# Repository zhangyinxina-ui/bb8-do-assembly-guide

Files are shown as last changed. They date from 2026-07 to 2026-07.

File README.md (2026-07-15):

# BB-8 & D-O 1:1 Assembly Guide

[中文在线装配网站](https://zhangyinxina-ui.github.io/bb8-do-assembly-guide/) · [English build guide](https://zhangyinxina-ui.github.io/bb8-do-assembly-guide/en/) · [权利与再分发边界](NOTICE.md)

一个面向个人制作者的公开工程记录：包含《星球大战：原力觉醒》BB-8 的 1:1 屏幕参考 Blender 模型、三视图、内部运动机构、运动学/动力学验证、控制器草案，以及 D-O 合法公开资源和采购门控路线。

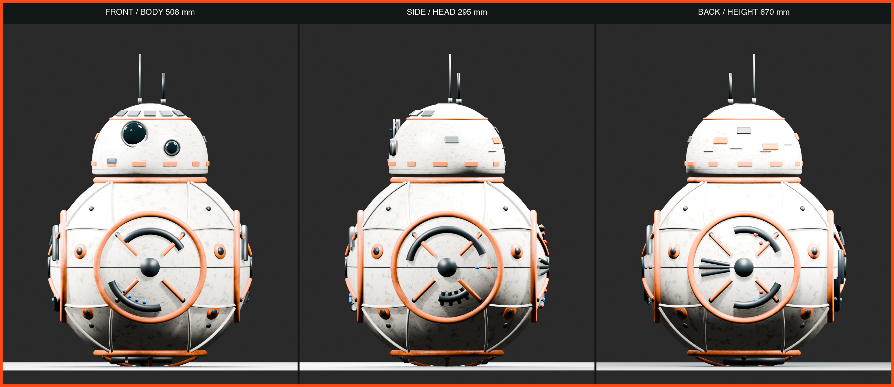
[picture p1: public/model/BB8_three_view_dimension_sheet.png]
BB-8 三视图


## 当前基准

- BB-8 身体球：Ø508 mm。
- 头部最大直径：Ø295 mm。
- 无天线总高：670 mm，对齐 StarWars.com 公开的 0.67 m。
- Blender 主工程 Stage 19 重开审计：386 个总对象、182 个内部对象，其中 150 个制造对象、9 个非制造工程标记和 23 个 `non_fabrication_reference` 预 CAD 门控对象；主文件 SHA-256 为 `ecd9a8b02db7c0b253c06005aaf16e7a8bf10147f8adec9c8900415e18b38af4`。
- 阶段14质量账本：名义8.463 kg、名义质心z=-56.2 mm、最不利角点z=-27.7 mm；0.6 N·m连续扭矩按2×余量时目标加速度降额为0.70 m/s²。17组质量仍需实物称重。
- 双轮差速内车、310 mm 轮距、6+6 磁体随动头和 40 N 装机拉脱力验收合同。
- 编码器轮速 PI + IMU 偏航闭环仿真：直线 RMS 误差 0.00772 m/s、转角 91.20°，传感器过期同周期撤销 PWM。
- ESP32-S3 已编译双正交编码器与 MPU6050 适配；CPR默认为0、静止标定未完成时保持拒动。
- 双 INA226 电流适配、开漏 ALERT、显式限值、过流/堵转回放与11类锁存故障已编译验证；阶段19将原ALERT→EN假设改为适配MDD20A的ALERT_N→PWM许可级，实体测试仍为 `NOT_RUN`。
- 阶段15新增左右电机驱动包络、双散热器、主保险丝、常开接触器、双通道常闭急停、安全继电器、维护断电与系留急停插口；3°动态坡道解析点为0.289 N·m/电机、2.07×连续扭矩裕量和4.22°合成倾角。器件型号与实体测试仍未冻结。
- 阶段16新增19项强制真机调试门、固定字段ESP32遥测解析器和带文件SHA-256的证据审计；当前结果为 `HOLD_PHYSICAL_TESTS_NOT_RUN`，0/19通过。
- 阶段17用厂商官方资料筛选MDD20A、30 A MIDI保险丝、SW60接触器和P28A 4S2P候选；15/15额定检查通过，但因堵转、再生、独立去能适配、BMS与电池包未冻结，结果保持 `HOLD_COMPONENT_FREEZE_MEASUREMENTS_REQUIRED`。
- 阶段18完成REC Active BMS 4S、MDD20A、SW60、MIDI保险丝、外置分流器与双通道门板的模块化电源舱解析布局，并已写入唯一Blender主工程；重开审计确认363个总对象、159个内部对象、150个制造对象、9个工程标记和39个阶段18对象。8个候选包络满足球壳/候选/既有机构间隙门，但12项实物尺寸与接口仍未冻结，结果保持 `HOLD_PHYSICAL_FIT_AND_INTERFACE_VALIDATION_REQUIRED`。
- 阶段19发布双许可PWM门正式KiCad 10原理图与50 × 35 mm两层布线PCB，并把23个非制造板件/器件参考包络写入唯一Blender主工程；重开审计与新导出已通过。SAFE_A、SAFE_B、双INA226 `ALERT_N`与3.3 V掉电均可独立阻断左右PWM；64/64真值组合、0项ERC违规、0项PCB DRC违规、0个未连接项，以及34个器件引用/91条规范引脚连接/21个网络交叉审计通过。但尚无独立原理图/布局同行复核、Gerber/钻孔发布复核、实装板或台架波形，结果保持 `HOLD_PCB_CAD_BENCH_AND_SAFETY_VALIDATION_REQUIRED`。
- 阶段20发现并封锁旧结构分析漂移：当前制造清单的磁力桅杆是Ø24 × 340 mm，而阶段2仍按Ø12/Ø8 × 300 mm铝管计算。新门以当前数字几何筛查2.5 g垂向/1.0 g侧向载荷、斜撑屈曲、纵梁/横梁挠度、PCD35电机安装需求、理想基材疲劳和桅杆模态；解析检查通过，但轮—壳接触还缺5.5 mm径向调节预算，15项材料/连接/公差/实物门全部未关闭，结果保持 `HOLD_JOINT_TOLERANCE_MATERIAL_AND_PHYSICAL_VALIDATION_REQUIRED`。
- D-O v3.4.3 的 D0/D1 舵机—Serial0 冲突已形成固定哈希安全变体：四路舵机移到 D22–D25，Mega 2560 编译仍为 Flash 17% / RAM 18%，并生成版本锁定线束合同；实体导通、USB/Serial0、四路脉宽与失效保护仍为 `NOT_RUN`，不放行舵机电源。
- 24 步装配指南与19项真机门；浏览器进度不能替代真机证据。

这些拆分尺寸和外观细节来自公开画面、社区摄影测量和制作者资料，不是 Lucasfilm 官方 CAD，也不应宣称逐毫米复制电影道具。

## 仓库结构

| 路径 | 内容 |
| --- | --- |
| `blender/` | 参数化生成器、主工程、阶段检查点、审计和导出脚本 |
| `engineering/` | 物理输入、计算结果、D-O 清单和采购门控 |
| `firmware/` | BB-8 C++ 控制核心与 ESP32-S3 适配草案 |
| `docs/` | 从阶段 1 到阶段 20 的中英文设计、验证和续接记录 |
| `hardware/` | 阶段19双许可PWM门正式KiCad原理图、两层布线PCB与OpenSCAD机械包络；不含Gerber/钻孔发布包 |
| `app/` | Vinext/Next 开发网站 |
| `github-pages-src/` | GitHub Pages 纯静态 React 入口 |
| `public/` | 网站公开的图像、GLB、STL、CSV 和说明文件 |
| `tools/` | 运动学、物理、磁耦合、真机证据、D-O 与 Pages 审计工具 |

## 本地运行

要求 Node.js 22.13.0 或更高版本、Python 3，以及可选的 Blender 5.1.x。

```bash
npm ci
npm run dev
```

构建并审计 GitHub Pages 静态网站：

```bash
npm run build:pages
```

完整网站回归测试：

```bash
npm test
npm run lint
```

主要工程验证：

```bash
python3 tools/verify_kinematics.py
python3 tools/verify_physics.py
python3 tools/verify_multibody.py
python3 tools/verify_differential_turn.py
python3 tools/verify_motor_selection.py
python3 tools/verify_magnetic_coupling.py
python3 tools/verify_mass_properties.py
python3 tools/verify_stability_envelope.py
python3 tools/verify_commissioning_evidence.py
python3 tools/verify_power_component_selection.py
python3 tools/verify_power_cassette_layout.py
python3 tools/verify_dual_permissive_gate.py
python3 tools/verify_stage19_kicad.py
python3 tools/verify_stage19_kicad_pcb.py
python3 tools/verify_stage20_structural_load_path.py
python3 tools/audit_do_resources.py
sh tools/run_closed_loop_sim.sh
```

阶段 10 的闭环运动证据见 [编码器 / IMU 闭环运动仿真](docs/BB8_阶段10_闭环运动仿真.md) 和 [200 Hz 遥测](engineering/closed_loop_telemetry.csv)。软件仿真通过不等于真机地面验收。

阶段 11 的传感器代码、默认拒动策略和上电标定顺序见 [ESP32 编码器与 MPU6050 适配](docs/BB8_阶段11_ESP32传感器适配.md) 与 [机器可读接口合同](engineering/sensor_adapter_contract.json)。

阶段 12 的双 INA226、开漏ALERT、显式限值和故障回放见 [电流保护与堵转回放](docs/BB8_阶段12_电流保护与堵转回放.md)、[机器可读电流合同](engineering/power_safety_contract.json) 和 [5 ms回放记录](engineering/power_safety_replay.csv)；当时的EN假设已由阶段19适配为MDD20A的PWM硬件门。

阶段 13 把这条保护链落实到110件内部总成，见 [电流保护硬件建模与重开审计](docs/BB8_阶段13_电流保护硬件建模.md) 和 [110件装配尺寸清单](engineering/internal_assembly_manifest.csv)。

阶段 14 增加可拆卸密封低位配重盒，并以17组质量账本、全部最小/最大角点和刚体惯量替代旧110 mm假设，见 [中文验证报告](docs/BB8_阶段14_质量质心与惯量验证.md)、[English validation report](docs/BB8_stage14_mass_cg_inertia_validation.md) 和 [当前内部装配清单](engineering/internal_assembly_manifest.csv)。

阶段 15 把驱动器与硬件去能链落实为30个新内部对象，并新增斜坡、牵引、转弯、倾角和磁头合载荷扫描，见 [中文阶段15报告](docs/BB8_阶段15_驱动电源与动态稳定性.md)、[English Stage 15 report](docs/BB8_stage15_drive_power_dynamic_stability.md) 和已由阶段19重导出的 [150件制造清单](engineering/internal_assembly_manifest.csv)。未提供机械驻车制动，因此断电坡道保持明确为不支持。

阶段 16 不新增 `.blend` 副本，而是把真实硬件运行转换为19项可审计门：固定字段串口遥测、测量值、证据文件和SHA-256必须同时存在，空填PASS会被拒绝。见 [中文阶段16报告](docs/BB8_阶段16_真机调试证据门.md)、[English Stage 16 report](docs/BB8_stage16_physical_commissioning_evidence_gate.md)、[测试矩阵](engineering/commissioning_test_plan.json)、[证据模板](engineering/commissioning_evidence.json) 和 [当前HOLD结果](engineering/commissioning_results.json)。

阶段 17 将通用电气包络收敛为官方资料支持的候选，但不越过实物证据边界：MDD20A额定裕量足够，却没有独立EN且再生路径未冻结；30 A MIDI必须用堵转波形做I²t配合；SW60普通续流二极管的35 ms典型释放时间超出20 ms合同；4S BMS尚未冻结。见 [中文阶段17报告](docs/BB8_阶段17_驱动电源器件选型门.md)、[English Stage 17 report](docs/BB8_stage17_drive_power_component_selection_gate.md)、[候选矩阵](engineering/power_component_candidates.json) 和 [当前HOLD结果](engineering/power_component_selection_results.json)。

阶段 18 将候选器件收敛为可拆卸模块化驱动电源舱：REC Active BMS 4S按111 × 135 × 44 mm外壳、MDD20A按88.90 × 78.74 mm官方板框、SW60按81 × 37 × 28.1 mm包络进入解析布局。当前最小球壳余量27.643 mm、候选件间隙7.500 mm、与既有机构间隙6.000 mm；这些只证明数字包络未冲突，不代替实物孔位、接插件、线束弯曲、散热与维护验证。几何已覆盖保存到唯一主工程并在重开后通过审计，主文件SHA-256为 `3b774f3e02c89e15922aac48629a43d4765d37078acad88ccf34f6316827d5c3`。见 [中文阶段18报告](docs/BB8_阶段18_模块化驱动电源舱布局门.md)、[English Stage 18 report](docs/BB8_stage18_modular_drive_power_cassette_layout_gate.md)、[布局输入](engineering/stage18_power_cassette_layout.json) 和 [当前HOLD结果](engineering/stage18_power_cassette_results.json)。

阶段 19 将门板占位收敛为正式原理图与布线PCB/DRC参考设计：2个VO617A-4隔离SAFE_A/B，3片SN74LVC2G08依次门控SAFE_A、SAFE_B和双INA226 `ALERT_N`；2.00 kΩ/0.5 W输入支路在12.0–16.8 V解析为5.175–7.900 mA，64行真值表证明任一许可丢失均使两路PWM为低。23个板件/器件包络已作为非制造参考写入唯一主工程，重开后确认386个总对象、182个内部对象、150个制造对象、9个工程标记和23个Stage 19对象；STL/GLB、制造清单与内部三视图已重导出。KiCad 10.0.4正式原理图为0项ERC违规；50 × 35 mm两层PCB含38个封装、1614段走线、54个过孔、F.Cu 3V3和B.Cu GND铜区，DRC为0项违规/0个未连接项。临时重生成板与跟踪板的UUID无关结构哈希一致，XML网表与34个器件引用、91条规范引脚连接和21个网络全部一致。仍没有独立原理图/布局同行复核、Gerber/钻孔发布复核、实装板或20 ms示波器证据。见 [中文阶段19报告](docs/BB8_阶段19_独立双许可PWM硬件门.md)、[English Stage 19 report](docs/BB8_stage19_independent_dual_permissive_pwm_gate.md)、[原理图验证结果](engineering/stage19_kicad_verification.json)、[PCB验证结果](engineering/stage19_kicad_pcb_verification.json)、[PCB DRC报告](engineering/stage19_kicad_pcb_drc.json)、[Blender重开证据](engineering/stage19_blender_reopen_audit.json)、[机器合同](engineering/stage19_dual_permissive_gate_contract.json) 和 [当前HOLD结果](engineering/stage19_dual_permissive_gate_results.json)。

阶段 20 将结构解析重新绑定到当前Stage-19制造清单，并明确标记阶段2的Ø12/Ø8 × 300 mm桅杆已被当前Ø24 × 340 mm包络取代。Ø24/Ø20管材和Ø12/Ø8斜撑只是待冻结候选；2.5 g垂向/1.0 g侧向闭式筛查得到桅杆3.273 MPa、两根纵梁22.814 MPa和0.670 mm挠度，解析裕量通过。PCD35电机面板只报告每颗M4的18.25 N合成需求，不宣称未知等级紧固件已通过。理想6061-T6/T651基材、模态和名义锁扣比值同样只作筛查；轮—壳接触的5.5 mm调节短缺、材料证书、接头、壳体接触、应变、冲击、锤击模态、耐久与19项真机门仍保持开放。见 [中文阶段20报告](docs/BB8_阶段20_结构载荷与公差门.md)、[English Stage 20 report](docs/BB8_stage20_structural_load_and_tolerance_gate.md)、[机器合同](engineering/stage20_structural_load_contract.json)、[当前HOLD结果](engineering/stage20_structural_load_results.json) 和 [载荷扫描](engineering/stage20_structural_load_sweep.csv)。

## D-O 公开资源边界

仓库不冒充拥有 D-O 整机机械文件：

- Printed Droid 公开仓库固定审计到提交 `e90aacdbe26a62fd4f0229d5504a3f2f3c409055`。
- 公开仓库包含 5 个 Arduino 草图，但整机机械 CAD/STL 数量为 0。
- v1.1、v2.1、v3.4 使用个人非商业条款，不能笼统称为 OSI 开源。
- Printed Droid 控制板页的 12 个公开附件已下载到 Git 忽略目录并逐项固定 SHA-256；公开可下载不等于允许本仓库镜像再分发。
- AIO32 v2.1 附件含 22 个源码文件，已用 ESP32 core 3.3.7 实编译通过（Flash 41%、RAM 15%），并发现手册遗漏 SensorLib 依赖；但整包仍无统一 LICENSE、KiCad/Gerber 或机械模型，其手册所称共享仓库硬件文件在当前唯一 `main` 分支中未找到，保持许可与硬件 CAD 双 HOLD。
- Mr Baddeley D-O V2 机械包属于付费资源，本仓库不包含。
- Mantis 播放列表的5集编号构建视频与1个轮胎视频描述已逐条审计；描述没有发布 Matt 改版 CAD 或控制源码，详见 [机器审计](engineering/do_mantis_video_audit.json)。
- 许可不明确的调试支架、第三方 PDF、本地工具链和编译缓存不会推送到 GitHub。

详见 [D-O 资源审计与自组入口](docs/DO_资源审计与自组入口.md)、[D01-D16 自组路线](docs/DO_自组采购与调试路线.md) 和 [26 项采购门控 BOM](engineering/do_self_build_bom.csv)。`DO-SRC-001` 已有 D22–D25 可编译变体但仍等待实体连续性；`DO-SRC-002` 已有版本/哈希绑定线束合同但仍等待逐网导通；`DO-SRC-003` 将官网仍为 v3.4.0 的泛名 ZIP 降为历史参考，当前转换输入只使用固定 GitHub v3.4.3。

## 自动部署

推送到 `main` 后，`.github/workflows/deploy-pages.yml` 会：

1. 安装固定依赖；
2. 构建 `/bb8-do-assembly-guide/` 子路径静态站点；
3. 扫描本机绝对路径、GitHub 令牌和禁止发布的 `.blend` 网站副本；
4. 上传 Pages artifact 并部署到 GitHub Pages。

## 免责声明

这是非官方粉丝研究、个人教育和工程原型。STAR WARS、BB-8、D-O 及相关角色归各自权利人所有。除非文件单独声明许可证，本仓库公开可见不等于自动授予商用、复制或再分发许可。使用前请阅读 [NOTICE.md](NOTICE.md)。

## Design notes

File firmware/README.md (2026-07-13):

# BB-8 双电机控制核心

## 当前状态

`controller_core.*` 是不依赖 Arduino/ESP32 SDK 的控制核心；`sensor_math.*` 是编码器/IMU换算层；`power_safety.*` 是电流阈值、新鲜度与堵转计时层；`esp32_bb8/` 是已通过 ESP32-S3 编译的硬件适配草案。

已实现：

- `v / ω` 到左右轮速差速混控
- 线速度和角速度斜坡限制
- 编码器左右轮速 PI 闭环与 IMU 偏航率差动修正
- IMU/编码器新鲜度和两类偏航测量一致性检查
- 四边沿正交解码、轮速低通、运动指令后750 ms无脉冲停机
- MPU6050地址探测、±4g/±500°/s配置、400样本静止陀螺零偏标定和30 ms超时
- 双 INA226、2 mΩ Kelvin分流、20 ms新鲜度和200 ms寄存器回读门槛
- 每次上电显式配置瞬时电流/堵转电流/持续时间，默认拒动
- INA226 ALERT、测量过流、电流传感器过期和持续堵转锁存
- 左右输出按最大轮速同比例饱和
- 13.2–14.3 V 之间连续功率降额，避免低电量峰值电流触发压降停机
- 12 V 电机母线归一化：4S 满电 16.8 V 时占空比上限 71.4%，避免电机过压
- 急停、遥控丢失、运动传感器过期/不一致、电流传感器过期、硬件电流告警、过流、堵转、欠压、过温、过度倾斜共11类锁存故障
- 只有当所有传感器恢复安全后才允许手动复位

## 本地验证

```bash
clang++ -std=c++20 -Wall -Wextra -Werror \
  firmware/controller_core.cpp tests/controller_core_test.cpp \
  -o build/controller_core_test
./build/controller_core_test
sh tools/run_closed_loop_sim.sh
sh tools/run_power_safety_replay.sh
npm run test:firmware
```

预期输出：

`PASS controller_core: closed-loop feedback, derating, saturation, and 11 fail-safe paths`

闭环仿真会生成 `engineering/closed_loop_telemetry.csv`，电流故障回放会生成 `engineering/power_safety_replay.csv`。两者都是确定性软件证据，不等于真机地面验证。

阶段16把ESP32每200 ms输出的真机遥测扩展为带单调毫秒时间戳的固定字段：命令速度、使能、故障、电池、温度、急停、遥控、IMU、编码器、轮速、电流、硬件ALERT和PWM。将串口监视器原始文本保存后，可运行：

```bash
python3 tools/parse_bb8_telemetry.py \
  --input evidence/run-001/serial.log \
  --output evidence/run-001/telemetry.csv \
  --summary evidence/run-001/telemetry_summary.json
```

解析器只整理真实记录，不会把软件仿真或示例日志转成物理验收PASS。物理记录还必须按 `engineering/commissioning_test_plan.json` 补齐仪表、照片/视频、测量值和SHA-256，再由阶段16验证器审计。

## ESP32 硬件适配合同

200 Hz 主循环必须执行：

1. 更新 RC 帧并计算最后有效帧年龄；超过 100 ms 将 `remote_ok=false`。
2. 从独立常闭急停回路读取 `emergency_stop`；不得只用软件按钮。
3. 电池电压必须经电阻分压和 ADC 标定；默认 4S 欠压门槛 13.2 V。
4. 电机温度传感器脱落必须视为故障，不能当作低温。
5. IMU 与编码器数据必须带时间戳；任一过期或二者偏航率差异超过门槛都必须锁存停机。
6. 两路高侧电流数据必须带时间戳；INA226校准/配置回读错误、未配置限值或数据超过20 ms都必须停机。
7. 两路开漏 ALERT 必须除了进入 GPIO 14，还进入阶段19外部硬件门，直接把MDD20A左右PWM拉低；MDD20A没有独立EN，真正去能仍由安全继电器和常开接触器完成。
8. 调用 `Controller::update(0.005F, command, sensors)`。
9. `enabled=false` 时必须在同一循环内拉低驱动器 EN 硬件引脚，而不只把 PWM 设为零。

## ESP32-S3 编译验证

本项目已用 Arduino CLI 1.5.1 与官方 Arduino-ESP32 3.3.10 对通用 ESP32-S3 目标完成本地编译：

```bash
arduino-cli compile \
  --fqbn esp32:esp32:esp32s3 \
  --config-file .arduino/arduino-cli.yaml \
  --build-path build/esp32_bb8 \
  firmware/esp32_bb8
```

阶段 10 编译结果：程序 338051 bytes（25%），全局变量 22492 bytes（6%）。这只证明源码与当前官方工具链兼容，尚未上传开发板，也未进行带电电机试验。

阶段 11 传感器适配编译结果：程序 367791 bytes（28%），全局变量 24636 bytes（7%）。

阶段 12 电流保护适配编译结果：程序 369971 bytes（28%），全局变量 24676 bytes（7%）。

阶段 16 固定字段真机遥测编译结果：程序 370095 bytes（28%），全局变量 24676 bytes（7%）。

台架串口协议：

1. 上电后保持底盘静止约2秒，等待 `IMU_READY`。
2. 依据实测编码器数据发送 `E <每轮转四边沿计数> <左方向±1> <右方向±1>`；默认CPR为0，未配置时电机EN保持关闭。
3. 依据限流电源下的实测发送 `I <瞬时切断_A> <堵转判定_A> <堵转持续_ms>`；限值默认未配置。
4. 以至少10 Hz发送 `V <线速度m/s> <角速度rad/s>`；先发送 `V 0 0`。
5. 全部传感器安全且最新指令严格为 `V 0 0` 后发送 `R` 清除故障锁存；非零命令下复位会被拒绝。超过100 ms未收到速度帧会停机。

CPR、方向和电流限值都不会写入非易失存储，每次上电都必须重新确认。

## 建议硬件映射（ESP32-S3）

| 信号 | 建议引脚 | 要求 |
|---|---:|---|
| 左 PWM / DIR | GPIO 4 / 5 | PWM 至少 20 kHz |
| 右 PWM / DIR | GPIO 6 / 7 | PWM 至少 20 kHz |
| 驱动 EN | GPIO 8 | 外部下拉，MCU 复位时为禁用 |
| 急停返回 | GPIO 9 | 常闭回路，断线即停机 |
| 左编码器 A/B | GPIO 10 / 11 | 屏蔽双绞线 |
| 右编码器 A/B | GPIO 12 / 13 | 屏蔽双绞线 |
| 电流 ALERT | GPIO 14 | 双 INA226 开漏并联；同时进入阶段19硬件门的 `ALERT_N` 许可级 |
| IMU I²C SDA/SCL | GPIO 17 / 18 | 3.3 V，短线 |
| 电池 ADC | GPIO 1 | 分压+输入保护 |
| 温度 ADC | GPIO 2 / 3 | 左右电机分开采样 |

> 引脚仅是建议映射，必须对照所选 ESP32-S3 开发板原理图排除启动绑定、USB/JTAG 和 Flash/PSRAM 占用引脚。

## 真机前未完成的门槛

- 软件适配已实现并编译，但尚未接入真实MPU6050、编码器和电机验证。只有完成静止标定、显式CPR配置且数据持续新鲜时，`imu_fresh`与`encoders_fresh`才可能为真。
- 当前正交编码器使用GPIO CHANGE中断而不是ESP32 PCNT硬件；必须在目标最高转速下测量中断负载和丢计数，再决定是否迁移到PCNT。
- INA226适配、软件过流/堵转判定和ALERT配置已编译；阶段19已给出ALERT/SAFE_A/B→PWM预CAD合同，但实体2 mΩ分流、Kelvin布线、正式PCB、驱动器硬限流与急停回路仍未验证。
- 必须在轮子架空时标定方向、比例和电流上限。
- 必须有物理急停、保险丝、独立驱动 EN 和围栏后才可落地。

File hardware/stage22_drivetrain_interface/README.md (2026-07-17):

# Stage 22 drivetrain interface

This package corrects the Stage-21 non-catalogue `5M-280-15` belt candidate and closes the analytical bearing, shaft, key and rail-interface load path. It is **reference CAD only**, not a fabrication release.

The selected reference architecture uses:

- Gates `5MGT-300-15`, product `92706002`, 300 mm pitch length, 60 teeth and 15 mm width;
- equal candidate 24-tooth 5MGT pulleys at 90 mm centre distance;
- two candidate 6001 sealed bearings per cassette, 38 mm bearing-centre span;
- a 12 mm keyed shaft with candidate 4 × 4 × 20 mm DIN 6885 key engagement;
- two 6 mm reamed dowels, four M6 clamps and a hard stop per cassette;
- a removable outboard pulley and guard for safe belt installation.

## Build the reference outputs

Run:

```sh
tools/build_stage22_drivetrain_interface_cad.sh
```

The dependency-light builder creates two nominal DXF profiles, a keyed-shaft envelope STL, an assembly-envelope STL, an engineering review PNG and a SHA-256 manifest in `outputs/`. The editable OpenSCAD source is supplied alongside them.

## Assembly order

1. Machine the shaft, keyway, hubs, bearing seats, retainers and rail bracket only after supplier fit tables, material certificates and GD&T are frozen.
2. Press or slide the selected bearings using the supplier-prescribed ring support; retain the outboard bearing and preserve at least 0.3 mm axial float at the inboard bearing.
3. Install the wheel hub between the bearing supports, then fit the keyed shaft and positive axial retainers.
4. Locate the cassette with both 6 mm dowels and the hard stop before tightening the four M6 clamps.
5. Fit the motor pulley, wheel pulley and belt as one serviceable stack by removing the outboard pulley and guard; never force the belt over two flanges.
6. Set belt tension from Gates DesignFlex or a supplier calculation, then record the measurement method and cold/hot values.
7. Perform the 7.2 Nm keyed-joint torque proof, raised-wheel spin/e-stop test, shell clash/service audit and the complete nineteen-item physical commissioning gate.

## Release boundary

The analytical screen passes, but supplier power rating and installation tension, bearing clearance and fits, shaft/hub drawings, materials, dowel ream and GD&T, guard fasteners and service access, Blender clash, tire/shell wear, yaw calibration, thermal/endurance and physical commissioning remain on HOLD. The user's current Blender master is intentionally not changed or saved by Stage 22.

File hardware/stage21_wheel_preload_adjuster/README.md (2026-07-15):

# Stage 21 tangent-wheel preload cassette

This directory contains **reference CAD only** for the Stage-21 BB-8 powered-wheel correction. It is not a fabrication release.

The current Blender wheel is a 96 × 26 mm finite cylinder with its axle along global X. Exact support geometry leaves about 5.07 mm to the 254 mm inner shell and the axle misses the local tangent plane by about 48.8°. The reference cassette therefore:

- cants the wheel axle tangent to the local shell;
- moves the IG42 motor 80 mm radially inward on a parallel axis;
- uses candidate equal 24T, 5 mm-pitch pulleys and a 280 mm / 56-tooth belt;
- carries the wheel on two candidate 6001-2RS bearings and a 12 mm shaft;
- gives 12 mm radial travel with an M6×1 jackscrew, hard stops and four M6 clamps;
- uses a 0.75 mm parabolic crown drop across the 26 mm wheel width.

## Build the reference outputs

Run:

```sh
tools/build_stage21_wheel_preload_cad.sh
```

When OpenSCAD is available, the script exports the assembly, fixed/moving plates, jackscrew block, crowned-wheel envelope, two DXF profiles and a review PNG into `outputs/`.

If OpenSCAD is unavailable, the checked-in Python fallback creates exact 2D DXF cut profiles, an exact crowned-wheel STL, reference-envelope STL files and the review PNG without installing anything. In that fallback, the plate STL files are deliberately named `*_envelope.stl`: use the DXF—not the envelope STL—for holes and slots.

## Safety and release boundary

The DXF and STL files are fit references. Do not manufacture a running robot from them until the open gates in `engineering/stage21_wheel_preload_contract.json` are closed. In particular, bearing fits, shaft/hub retention, belt rating and tension, guards, plate material, M6 preload, shell contact strength, tire compound and measured 60–100 N wheel preload are not frozen. The current open Blender master is intentionally not modified by this package.

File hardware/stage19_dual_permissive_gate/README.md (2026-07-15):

# Stage 19 dual-permissive PWM gate — routed PCB/DRC reference design

This package replaces the Stage-18 empty gate-board placeholder with a reviewable electrical contract, deterministic KiCad 10 schematic and a real 50 × 35 mm two-layer routed PCB. KiCad 10.0.4 reports **0 ERC violations, 0 PCB DRC violations and 0 unconnected items**. The 34 electrical references, 91 pin assignments and 21 named nets match the canonical CSV; the PCB adds four contracted 3.2 mm M3 NPTH mounting holes. It is deliberately **not a fabrication release**: independent schematic/layout peer review, intentional Gerber/drill review, fabrication, continuity, power-up and bench waveforms remain absent.

## Intended function

```mermaid
flowchart LR
  MCU[MCU PWM L/R] --> A[U3: AND SAFE_A_OK]
  A --> B[U4: AND SAFE_B_OK]
  B --> C[U5: AND ALERT_N]
  C --> MDD[MDD20A PWM L/R]
  SA[12–16.8 V permissive A] --> OA[VO617A-4 A]
  SB[12–16.8 V permissive B] --> OB[VO617A-4 B]
  OA --> A
  OB --> B
  INA[Dual INA226 open-drain ALERT] --> C
  REL[Safety relay] --> SA
  REL --> SB
  REL --> SW60[Normally-open main contactor]
```

Both outputs follow:

`PWM_OUT = LOGIC_POWER_OK AND PWM_IN AND SAFE_A_OK AND SAFE_B_OK AND ALERT_N`

Either safety channel, a current ALERT, or loss of 3.3 V forces both PWM outputs low. `DIR_L` and `DIR_R` pass through directly and are not safety signals. The contract therefore requires MDD20A sign-magnitude mode, where PWM low is brake.

The board provides six declared test points: `SAFE_A_OK`, `SAFE_B_OK`, `ALERT_N`, `PWM_L_OUT`, `PWM_R_OUT` and `GND`. The PCB-plus-component envelope is 11.4 mm; including the 3.0 mm insulated mounting stack gives 14.4 mm installed height and only 0.6 mm analytical margin inside the Stage-18 keepout.

## Safety boundary

- PWM low is braking, not energy isolation. The independent safety relay and normally-open contactor must still remove the motor bus.
- This is not a safety PLC, certified safety relay or redundant safety controller. Shared power, PCB, connectors, logic packages and the motor driver remain common-cause paths.
- The VO617A-4 CTR and saturation checks in this repository use the manufacturer's 25 °C test points. Its saturated 25 µs turn-off is a typical value, not a guaranteed maximum.
- An open `ALERT_N` wire can be pulled high by R13; that path is not fail-safe. Commissioning must test the sensor harness and MCU freshness latch separately.
- Do not fabricate or energise from these files. The formal schematic, routed layout and DRC are complete as a digital reference, but an independent peer review and intentional Gerber/drill release must happen before any manufacturer order or Stage-E02 bench test.

## Files

- `engineering/stage19_dual_permissive_gate_contract.json` — source-of-truth requirements and official references.
- `engineering/stage19_gate_netlist.csv` — pin-level connectivity contract.
- `engineering/stage19_gate_bom.csv` — provisional BOM; many passives remain manufacturer-TBD.
- `engineering/stage19_gate_truth_table.csv` — all 64 input combinations.
- `engineering/stage19_dual_permissive_gate_results.json` — analytical result and unresolved release gates.
- `stage19_dual_permissive_gate.kicad_sch` / `.kicad_pro` / `.kicad_pcb` — formal KiCad 10 schematic and routed two-layer PCB project.
- `stage19_symbols.kicad_sym` — project-local custom MCU-header and VO617A-4 symbols used by the deterministic capture.
- `engineering/stage19_kicad_erc.json` — KiCad 10.0.4 ERC export with zero violations.
- `engineering/stage19_kicad_netlist.xml` / `stage19_kicad_bom.csv` — machine-audited connectivity and KiCad BOM exports.
- `engineering/stage19_kicad_pcb_drc.json` — KiCad 10.0.4 PCB DRC report with zero violations and zero unconnected items.
- `engineering/stage19_kicad_pcb_verification.json` — structural regeneration, board envelope, mounting-hole, net and DRC evidence.
- `output/pcb/BB8_stage19_gate_pcb_*` — top/bottom copper review plots and a visually inspected isometric render; review images only, not Gerbers.
- `output/pdf/BB8_stage19_dual_permissive_gate_schematic.pdf` — reviewed one-page A4 schematic rendering.
- `tools/verify_stage19_kicad.py` — regenerates, runs ERC/exports and cross-audits the canonical netlist without granting fabrication release.
- `tools/generate_stage19_kicad_pcb.py` — deterministically places and routes the PCB with real KiCad footprints.
- `tools/verify_stage19_kicad_pcb.py` — regenerates the PCB in a temporary directory, compares UUID-independent structure and runs DRC on both copies.
- `tools/export_stage19_kicad_pcb.py` — exports review SVG/PNG files only; it cannot emit Gerber or drill manufacturing data.
- `tools/verify_dual_permissive_gate.py` — deterministic evaluator.
- `board_envelope.scad` — deterministic component-envelope model source. The local OpenSCAD 2021.01 CLI did not complete a headless export, so no STL is claimed in this stage.

## Required next tests

1. Independent peer review of the captured KiCad schematic and its safety assumptions.
2. Independent PCB placement/routing, creepage, courtyard, connector-polarity and test-point peer review; the automated DRC result alone is not release approval.
3. Intentionally generate and manually review Gerber/drill plots before any manufacturer order; none is published in this reference package.
4. Unpowered continuity and polarity inspection.
5. 12.0 V and 16.8 V corner tests for `SAFE_A` and `SAFE_B` independently.
6. Oscilloscope proof that each safety channel, `ALERT_N`, logic-power loss and MCU stuck-high drive both PWM outputs low within 20 ms.
7. 20 kHz PWM integrity, temperature, vibration, connector retention and EMC checks.
8. Combined safety-relay/contactor/PWM-gate Stage-E02 evidence.

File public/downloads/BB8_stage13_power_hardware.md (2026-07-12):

# BB-8 阶段 13：电流保护硬件建模与重开审计

> 结论：**双 INA226、双 2 mΩ 四线分流器、开漏 ALERT 汇接和独立驱动 EN 门已落实为 Blender 内部安装包络，并通过关闭后重新打开审计；真实板卡接线、脉冲额定、堵转和热试验仍为 `NOT_RUN`。**

## 新增的 22 个内部对象

| 对象组 | 数量 | 建模包络/合同 |
|---|---:|---|
| INA226 电流监测板 | 2 | 34 × 22 × 1.6 mm；地址 `0x40` / `0x41` |
| Kelvin 分流器 | 2 | 12 × 5 × 3 mm；2 mΩ、四线采样 |
| M2.5 可拆支柱 | 6 | 3 mm 安装高度；两监测板各2个，门板2个 |
| ALERT→EN 硬件门板 | 1 | 28 × 14 × 1.6 mm；MCU 停止执行时仍须能拉低双驱动 EN |
| 受监测高侧电源线 | 4 | 左右支路各输入/输出1条；最小弯曲半径30 mm |
| Kelvin 采样线 | 4 | 左右分流器各正/负1条；不可与大电流压降共用测量点 |
| 开漏 ALERT 线 | 2 | 左右 INA226 线与后汇接到硬件门 |
| 独立驱动 EN 线 | 1 | 失效低电平同时关闭两路驱动 |

这些对象安装在现有 104 × 80 × 12 mm 电子托盘上，板底与托盘顶面保持 3 mm 支柱间隙，并继承内车 `-4° → +4°` 俯仰动画。模型对象带有 `physical_test_status=NOT_RUN`，防止把几何布置误写成实物验证。

## 重开审计门

`blender/audit_bb8.py` 现在同时检查：

- 内部对象不少于110件，总对象保持314件；
- 两块 INA226 地址恰为 `0x40` / `0x41`；
- 两个分流器均为2 mΩ、四线连接，并保留脉冲额定实测门；
- 11条保护线的种类和数量固定为输入2、输出2、Kelvin 4、ALERT 2、EN 1；
- 三块电路板都落在电子托盘占地范围内，板底间隙为3 mm；
- 场景级实体试验状态必须保持 `NOT_RUN`；
- 原有508/295/670 mm、6个主面板、8个角区、驱动/磁头/线束和球壳包络门继续通过。

重开结果：

```text
PASS reopenable_blend engineering_stage=13 objects=314 internal=110 panels=6 triangles=8 rings=3/2/1 body=508mm head=295mm height=670mm
```

## 可追溯输出

- 主工程：`blender/output/BB8_1to1_screen_referenced.blend`
  - SHA-256：`5653ae72b029a4c770382bb6525e142e55fed60b0225811d9fb1149bd0434eac`
- 最终检查点：`blender/checkpoints/BB8_stage13_power_safety_hardware_v3.blend`
  - SHA-256：`244acfb60c706770e6bd03c08c76cb9eb8e049152bcd78e71a8b00bc60fa28e7`
- 内部机构 STL：`blender/exports/BB8_internal_mechanism_mm.stl`
  - SHA-256：`4427cc7410c61d39281e6c22748d0ca548c1616383fa8e3295839d79f5b226e4`
- 动画 GLB：`blender/exports/BB8_1to1_kinematic.glb`
  - SHA-256：`1585a883fb4cd93ae3380fb1d2773486e598ddf5707e7d9f7e959b1dcdc73de1`
- 自动装配清单：`engineering/internal_assembly_manifest.csv`，共110行对象记录。

## 下一道实体门

只有拿到真实 INA226 模块、2 mΩ 分流器、驱动器、电机、电池和线束后，才可执行：四线焊点核验、零点/量程标定、ALERT 断 MCU 试验、分流器脉冲温升、保险丝配合、架空堵转和封壳热平衡。未完成这些项目时，不得把本阶段标记为“硬件保护验证通过”。

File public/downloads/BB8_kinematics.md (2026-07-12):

# BB-8 运动学、控制架构与验证

## 设计边界

本方案是可制造的社区复刻架构：低重心双轮内车驱动球壳，顶部磁性桅杆耦合头部。它不是《原力觉醒》电影道具未公开的内部设计。

## 直线滚动关系

球体无滑动滚动：

`s = Rb · θb`

- `Rb = 0.254 m`
- 球体旋转 `360°` 的理论位移：`2πRb = 1.59593 m`
- 内部驱动轮半径 `Rw = 0.048 m`
- 球体一周对应驱动轮理论转数：`s / (2πRw) = 5.29167`

Blender 动画用线性插值将这一关系锁定在 1–120 帧（30 fps）：

- `RIG 00 - World travel`：位移 1.59593 m
- `RIG 10 - Rolling ball`：旋转 360°
- 两个 `Internal drive wheel`：各旋转 5.29167 周
- `RIG 20 - Gravity stabilised chassis`：加速时俯仰 -4°，匀速 0°，制动 +4°
- `RIG 30 - Magnetically coupled head`：保持世界竖直姿态目标

## 差速转向

左右驱动轮的外层控制可用标准差速映射：

`v = (vr + vl) / 2`

`ω = (vr - vl) / B`

`B` 是内车两轮接触中心间距。但内车通过球壳间接驱动地面，所以真机必须用编码器 + IMU 标定一个经验映射系数 `k_shell`，不能只靠开环理论值。

## 控制环

1. **200–500 Hz 安全环**：遥控丢包、倾角、过流、欠压、过温任一触发即零扭矩。
2. **200 Hz 电机速度环**：编码器 PID 左右独立闭环。
3. **100–200 Hz 车体姿态环**：IMU 估计内车俯仰/滚转，限制加速度防止内车翻越。
4. **50–100 Hz 头部目标环**：在磁耦合能力范围内保持头部质心位于球顶安全锥内。
5. **20–50 Hz 遥控命令环**：对速度和转向加斜坡限制，不直接跳变扭矩。

## 质心与稳定性验收

- 内车总质心建议低于球心 80–150 mm。
- 静止时将内车偏转 10°，释放后必须自动回复，无线束卡滞。
- 头部磁性载台在最大设计加速度下不得越过头底滚轮支撑多边形。
- 任一传感器故障不得让电机保持上一帧非零命令。

## 首台样机的保守运行包络

| 阶段 | 最高速度 | 最高加速度 | 头部 | 验收后才可进入 |
|---|---:|---:|---|---|
| 架空 | 轮子 10% PWM | 无 | 不安装 | 方向、编码器、急停正确 |
| 围栏内低速 | 0.10 m/s | 0.10 m/s² | 不安装 | 连续 10 次起停无翻车 |
| 围栏内跟头 | 0.15 m/s | 0.10 m/s² | 泡沫配重头 | 不脱落、不夹伤 |
| 室内样机 | 0.30 m/s | 0.20 m/s² | 完整头 | 急停距离和温升达标 |

## 数值验证

运行：`python3 tools/verify_kinematics.py`

输出 `blender/output/kinematics.csv`，并对一周位移、球体转角和驱动轮转数执行断言检查。

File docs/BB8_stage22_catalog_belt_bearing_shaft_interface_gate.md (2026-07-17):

# BB-8 Stage 22: Catalog Belt, Dual-Bearing Keyed Shaft and Rail Interface Gate

> **HOLD_SUPPLIER_FITS_TENSION_TORQUE_PROOF_AND_PHYSICAL_INTEGRATION_REQUIRED**. Catalog geometry, bearing life, keyed-shaft strength, positive rail load path and shell-envelope screens pass. Fabrication, Blender integration and physical release remain blocked.

## Correcting the Stage-21 belt candidate

- Gates' 2025 industrial catalog starts its standard 15 mm-wide 5MGT list at 300 mm. The Stage-21 **5M-280-15 / 280 mm / 56-tooth** candidate is not in that stock-length table.
- The replacement is official part **5MGT-300-15**, product 92706002: 300 mm pitch length, 60 teeth and 15 mm width.
- Equal 24T, 5 mm-pitch pulleys have 38.197 mm pitch diameter. A 90 mm center distance gives exactly **300.0 mm** closed pitch length at 1:1.
- Twenty-four teeth exceed Gates' 18-tooth 5MGT minimum recommendation. The motor mount provides 4.0 mm total adjustment, exceeding the catalog's 1 mm tensioning allowance.
- Do not force the belt over two flanges. Remove the guard and outboard wheel pulley, then install the belt together with that pulley. Gates DesignFlex or supplier power and installation-tension calculations remain mandatory.

## Dual 6001 bearing and overhung-pulley load path

- Conservative rating floors come from SKF W 6001-2RS1: 12×28×8 mm, C=4.42 kN, C0=2.36 kN and 16000 r/min limiting speed. This does not claim an SKF purchase.
- Bearing centers are 38 mm apart and the pulley center overhangs the outboard bearing by 14.5 mm. Three-times shock torque plus an 80 N-per-span pretension ceiling creates a 348.5 N pulley envelope and **532.8 N** worst equivalent bearing load.
- Static safety is 4.43; analytical L10 is **9516 h** even at 1000 r/min. Clearance, seals, fits, misalignment, contamination and temperature still require selected-part evidence.

## 12 mm keyed shaft, hubs and positive rail interface

- Under 3.6 N·m shock torque, pulley overhang and 100 N wheel preload, the ideal bending-torsion von Mises stress is 40.1 MPa. A 2.5 keyway factor raises it to **100.2 MPa**. Requiring certified yield of at least 400 MPa gives 3.99 analytical safety.
- A 4×4×20 mm key sees 7.5 MPa shear and 15.0 MPa bearing stress. A physical 7.2 N·m no-slip, no-permanent-set torque proof remains required.
- Each cassette uses two 6 mm dowels, four M6 clamps and a hard stop. At 1000 N interface load, dowel shear is 17.7 MPa, plate bearing 13.9 MPa and tear-out 4.6 MPa. No interface friction is credited.

## Packaging and assembly limits

- Moving to 90 mm center distance leaves 102.0 mm motor clearance, 13.1 mm plate clearance and 20.8 mm guarded-pulley clearance.
- These are local analytical envelopes, not a full current-master clash pass. Stage 22 did not save or overwrite the user's Blender master.

## Maker assembly and verification sequence

1. Cut inexpensive fit-test profiles first and confirm 90 mm center distance, 24T pulleys, the 300 mm belt and removable-pulley installation order.
2. Freeze the 12 mm shaft and 28 mm housing fits from the selected bearing supplier; locate one bearing and allow at least 0.3 mm float at the other, then measure endplay and outer-ring creep.
3. Machine the certified 12 mm keyed shaft and 4×4 keys, and pass the 7.2 N·m bench torque proof before installing the tire.
4. Feed each 1000 N cassette load into the chassis through two dowels and a hard stop; M6 fasteners clamp only. Guard removal must require isolated power.
5. Only then run raised-wheel belt tracking, E-stop, thermal, shell-contact, low-speed yaw-identification and nineteen-item commissioning tests.

Open freeze gates: 13. Manufacturing release is false and physical status is NOT_RUN.

## Official sources

- Gates 5MGT-300-15 product page: https://www.gates.com/us/en/power-transmission/synchronous-belts/poly-chain-synchronous-belts.p.9270-000000-000001.v.9270-06002.html
- Gates 2025 industrial catalog: https://www.gates.com/content/dam/documents-library/catalogs/industrial-power-transmission-catalogue-en.pdf
- Gates PowerGrip GT3 design manual: https://www.gates.com/content/dam/documents-library/catalogs/powergrip-gt3-drive-design-manual-en.pdf
- Gates preventive-maintenance manual: https://www.gates.com/content/dam/gates/home/knowledge-center/resource-library/operating-manuals/preventive-maintenance-manual-en.pdf
- SKF stainless deep-groove ball-bearing catalog: https://www.skf.com/binaries/pub12/Images/0901d19680406705-SKF-Stainless-steel-DGBB---11279_1-EN-Low-Res_tcm_12-259995.pdf

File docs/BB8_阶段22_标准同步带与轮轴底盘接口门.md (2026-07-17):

# BB-8 阶段 22：标准同步带、双轴承键轴与底盘接口门

> **HOLD_SUPPLIER_FITS_TENSION_TORQUE_PROOF_AND_PHYSICAL_INTEGRATION_REQUIRED**。目录几何、轴承寿命、键轴强度、正向定位接口与球壳包络解析筛查通过；制造、Blender写入和真机验证仍未放行。

## 先纠正阶段21的皮带候选

- Gates 2025工业目录的15 mm宽5MGT标准长度从300 mm起；阶段21的 **5M-280-15 / 280 mm / 56齿** 不在该标准库存长度表中。
- 改用官方产品 **5MGT-300-15**（产品号 92706002）：300 mm节线、60齿、15 mm宽。
- 两只24T、5 mm节距等径带轮的节径为 38.197 mm；90 mm轴距精确得到 **300.0 mm** 闭式节线，传动比仍为1:1。
- 24齿高于Gates对5MGT的18齿最小建议。电机安装位提供 4.0 mm总调节，超过目录的1 mm张紧余量。
- 双法兰条件不允许强行把皮带撬过法兰；规定先拆防护罩和轮侧可拆带轮，带轮与皮带一起装回。额定功率和安装张力仍必须用Gates DesignFlex或供应商计算冻结。

## 双6001轴承与悬臂带轮载荷

- 用SKF W 6001-2RS1的较保守目录值作评级下限：12×28×8 mm，C=4.42 kN，C0=2.36 kN，极限转速16000 r/min；未声称已经采购SKF轴承。
- 轴承中心跨距38 mm，带轮中心比外侧轴承悬出14.5 mm。3×冲击扭矩和每跨80 N预紧上界形成 348.5 N带轮径向包络，最重外侧轴承等效载荷 **532.8 N**。
- 静强度安全系数 4.43；即使按1000 r/min解析，L10仍为 **9516 h**。这不替代游隙、密封、配合、偏心、污染和温升实测。

## 12 mm键轴、轮毂与正向底盘接口

- 12 mm轴在3.6 N·m冲击扭矩、带轮悬臂和100 N轮压下，理想弯扭von Mises为 40.1 MPa；乘2.5键槽系数后为 **100.2 MPa**。要求材料证书屈服强度至少400 MPa，解析安全系数 3.99。
- 4×4×20 mm平键需求为剪应力 7.5 MPa、挤压应力 15.0 MPa；最终仍要做7.2 N·m无滑移、无永久变形的实物扭矩证明。
- 每侧底盘接口用2根6 mm定位销、4颗M6夹紧和一个硬限位；1000 N设计载荷下，定位销单剪 17.7 MPa、6 mm板孔挤压 13.9 MPa、边缘撕裂 4.6 MPa。强度筛查不借用摩擦力。

## 包络与装配限制

- 电机轴距增至90 mm后，电机球壳解析余量为 102.0 mm；板件最小余量 13.1 mm；含3 mm防护罩余量的带轮最小余量 20.8 mm。
- 这些是局部解析包络，不是当前用户Blender主工程的完整干涉通过结论；本阶段没有保存或覆盖该主文件。

## 自组装与验证顺序

1. 先按参考DXF做廉价样板，确认90 mm轴距、24T带轮、300 mm皮带和可拆轮侧带轮的装配顺序。
2. 用选定轴承供应商的配合表冻结12 mm轴和28 mm座孔；一端固定、一端至少0.3 mm浮动，再测端游和外圈爬动。
3. 加工带证书的12 mm键轴与4×4键，先在台架做7.2 N·m扭矩证明，再装轮胎。
4. 用两根定位销和硬限位把每侧1000 N载荷送入车架，M6只负责夹紧；检查防护罩必须在断电后才能拆。
5. 之后才允许进行架空皮带跑偏、急停、温升、球壳接触、低速偏航辨识和19项整机调试。

开放冻结门：13项；制造发布为否，物理试验状态为NOT_RUN。

## 官方来源

- Gates 5MGT-300-15产品页：https://www.gates.com/us/en/power-transmission/synchronous-belts/poly-chain-synchronous-belts.p.9270-000000-000001.v.9270-06002.html
- Gates 2025工业传动目录：https://www.gates.com/content/dam/documents-library/catalogs/industrial-power-transmission-catalogue-en.pdf
- Gates PowerGrip GT3设计手册：https://www.gates.com/content/dam/documents-library/catalogs/powergrip-gt3-drive-design-manual-en.pdf
- Gates预防维护手册：https://www.gates.com/content/dam/gates/home/knowledge-center/resource-library/operating-manuals/preventive-maintenance-manual-en.pdf
- SKF不锈钢深沟球轴承目录：https://www.skf.com/binaries/pub12/Images/0901d19680406705-SKF-Stainless-steel-DGBB---11279_1-EN-Low-Res_tcm_12-259995.pdf

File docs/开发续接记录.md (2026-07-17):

# BB-8 / D-O 开发续接记录

更新时间：2026-07-12 19:30（Asia/Shanghai）

## 当前可继续的主工程

- Blender：`blender/output/BB8_1to1_screen_referenced.blend`
- 建模生成器：`blender/create_bb8.py`
- 导出器：`blender/export_bb8.py`
- 重开审计：`blender/audit_bb8.py`
- 网站：`app/page.tsx`
- 物理参数：`engineering/physics_inputs.json`
- 物理验证器：`tools/verify_physics.py`

## 本阶段证据

- Blender 后台重开审计成功：292 个对象、88 个内部机构对象；GUI 同一进程无损重开阶段 9.3 主工程，当前仅 1 个 Blender GUI 进程且窗口无未保存星号。
- 场景元数据与可见几何：球体 508 mm、头部 295 mm、不含天线高度 670 mm。
- 身体、头部和内部机构 STL 以及 GLB 已从当前主工程重新导出，不再沿用旧外观文件。
- 阶段 1 物理解析模型在当前假设下 PASS：8.57 N 推进力、每电机 0.286 N·m、连续扭矩裕量 2.10×、磁保持裕量 2.51×。
- 网站构建及 2 项渲染回归测试通过。

## 文件指纹

- 主 `.blend`：`c4dd9fbd9a6f931992797ecbfa96d5a3559686047a40362821e7706e4b236ff0`
- 阶段 1 检查点：`6abceb677bfdd6b6bf13d89373fd49696c4f7c623092c28a5e4edbe72d4c5560`
- 阶段 2 检查点：`3ab31459d9aff2f7e7e3c92db93c5a4ac870eb6c74bf05abbb9dc13deb366133`
- 内部机构 STL：`4f5b67a637651efc8a223c7a63739cd1a7ba028972a56c118726261b8b7b0975`

## 未完成且不得误称完成

1. 外观仍是屏幕参考重建，尚未达到逐面板电影道具测绘精度。
2. 物理 PASS 基于假设输入，不是实物认证；需要称重、摩擦/预紧、扭矩电流、磁脱离力实测。
3. 编码器/IMU闭环、双INA226电流适配、过流/堵转回放和ESP32-S3编译已完成，但实体接线、参数辨识、ALERT→EN硬件门、热平衡、壳体接触/疲劳仍未完成。
4. D-O 付费 CAD 尚未购买；公开网站已部署到 `https://zhangyinxina-ui.github.io/bb8-do-assembly-guide/`。

## 下一步

拿到真实目标板、电机、驱动器、电池、MPU6050、编码器和双INA226板后，先核对GPIO/I²C、分流器额定与ALERT→EN外部门，再完成架空轮CPR/方向/IMU/电流标定，用阶跃响应替换仿真参数，随后进入封壳围栏低速验证。

## 阶段 2：多体、结构与电热（2026-07-12 14:27）

- 新增 `tools/verify_multibody.py`、`docs/BB8_多体结构电热验证.md` 和 `engineering/turning_multibody_sweep.csv`。
- 1.0 m/s、0.6 rad/s 转弯及冲击合载荷下，磁头解析保持裕量 2.31×。
- 12/8 mm、300 mm 铝管桅杆解析静态屈服裕量 18.52×；尚未计入疲劳、孔位和模态降额。
- 电机集总热模型估算设计点 38.9 °C。
- 低电量峰值电流会把 4S 电池拉到 12.55 V；控制核心已加入 13.2–14.3 V 连续功率降额并重新通过 ESP32-S3 编译。
- 阶段参数与扫描快照保存在 `engineering/checkpoints/stage02_multibody/`。

## 阶段 3：参数化内部总成（2026-07-12 14:31）

- 内部机构从 9 个示意对象增加到 25 个稳定标记对象。
- 新增左右电机座、四只随动稳定轮及支撑臂、左右桅杆三角支撑、两条电池固定带、电子托盘和保险丝/接触器包络。
- 生成内部正视、侧视、俯视三视图及组合图 `blender/output/BB8_internal_three_view.png`。
- 新增 `engineering/internal_assembly_manifest.csv`，记录每个机构对象的包络尺寸和世界坐标。
- 阶段检查点：`blender/checkpoints/BB8_stage03_buildable_internal_assembly.blend`。

## 阶段 4：真实电机候选与接触几何（2026-07-12 14:42）

- 厂家数据筛选首选候选：Sha Yang Ye / Cytron `IG42E-24K`，12 V、248 rpm、0.98 N·m额定扭矩、5.5 A额定电流。
- 96 mm轮理论额定地速1.25 m/s；相对0.286 N·m连续需求的额定扭矩裕量3.43×。
- Pololu 4692最大效率点扭矩约0.186 N·m，未作为当前连续工况首选。
- 内部电机包络更新为42 mm直径、100 mm保守总长、8 × 20 mm轴；对象数增至27。
- 修复此前驱动轮悬空问题：驱动轮中心位于206 mm接触半径，四只稳定球中心位于236 mm接触半径，审计公差±1 mm。
- 固件新增12 V电机母线归一化；4S满电16.8 V时PWM上限71.4%，ESP32-S3重新编译通过。
- 阶段检查点：`blender/checkpoints/BB8_stage04_IG42_contact_geometry.blend`。

## 阶段 5：真实电机面板、轮毂与拆装空间（2026-07-12 14:58）

- 从Cytron商品页关联的Sha Yang Ye `IG-42GM` 图纸确认：最大外径45 mm、24:1齿箱39.2 mm、电机段66 mm、8 × 20 mm轴、4×M4×6深/PCD35。
- 原阶段4的100 mm电机包络和150 mm轮距会造成左右电机实体重叠，已改为125.2 mm总包络和310 mm轮距，中央尾部间隙约19.6 mm。
- 主框由整板改为两根380 × 18 × 12 mm纵梁和8 mm中央横梁，避开电机实体；新增两块4 mm电机面板、8枚M4、两只26 × 40 mm键毂和6枚M5轮端紧固件包络。
- 内部对象增至45件；Blender重开审计新增电机中心检修间隙、PCD35实例、55 mm工具空间、球壳内包络和壳面接触检查。
- 控制器及90°转弯验证同步到310 mm轮距：0.3 m/s、0.8 m半径时左右轮为0.2419/0.3581 m/s。
- 新增 `docs/BB8_阶段5_电机安装与拆装.md`；键毂3×M5节圆和360/609 g重量来源冲突仍等待采购样件复测。
- 阶段检查点：`blender/checkpoints/BB8_stage05_verified_IG42_mount.blend`。

## 阶段 6：可拆球壳与显式线束（2026-07-12 15:00）

- 外观增加赤道连续分缝，内部增加494 mm密封圈包络和8个45°等分锁扣；单锁扣夹紧力合同暂定80 N。
- 左右IG42E分别建立动力线和编码器线：共12段显式线束、2个Molex 3.96 mm动力连接器和2个JST-PH 2.0 mm编码器连接器。
- 动力线最低弯曲半径合同30 mm，编码器20 mm；底盘边缘要求耐磨套，开壳前必须断开4个维护连接器。
- Blender重开审计扩展到70个内部对象，并验证8个锁扣、线束/连接器数量、弯曲半径合同、驱动轮保守包络10 mm避让及所有网格保持在球壳内。
- 新增 `docs/BB8_阶段6_球壳与线束维护.md`，包括开壳顺序和20次开合/手转10圈/低压架空测试门槛。
- 阶段检查点：`blender/checkpoints/BB8_stage06_serviceable_shell_harness.blend`。

## 阶段 7：磁性头部随动机构（2026-07-12 15:05）

- 内车顶端和头部底端各增加6个Ø20 × 6 mm磁体包络，面对面设计气隙8 mm；磁体等级、镀层和封装仍未冻结。
- 头底加入3只Ø24 mm非染色滚轮，按球面法向布置并从外侧接触254 mm球壳，另设独立滚轮载体环。
- 头部0.65 kg、2.5g垂向与1.0g横向冲击的合成载荷为17.16 N；2×最低值34.33 N，工程装机拉力验收线冻结为40 N。
- 新增 `tools/verify_magnetic_coupling.py`、`engineering/magnetic_coupling.json` 和 `docs/BB8_磁性头部耦合验证.md`；明确目录拉力不能替代实际壳体/气隙测力。
- Blender重开审计扩展到88个内部对象，验证6+6阵列、8 mm磁隙、40 N验收合同和三只滚轮球面接触。
- 阶段检查点：`blender/checkpoints/BB8_stage07_magnetic_head_follower.blend`。

## 阶段 8：D-O 合法自组资源与本机运行（2026-07-12）

- Printed Droid 控制仓库固定在提交 `e90aacdbe26a62fd4f0229d5504a3f2f3c409055`，推荐入口为 v3.4.3；共5个 Arduino 草图，仓库内整机机械 CAD/STL 为0。
- v1.1、v2.1、v3.4 各自 README 含个人非商业许可；旧 Mega/Nano 目录许可不明确，不能把整个仓库笼统称为开源。
- Printed Droid 的装配 PDF、接线 PDF 和 60 mm 无轮调试支架已保存并核验 SHA-256；调试支架并非整机结构件且无明确再分发许可，未放入网站下载区。
- `tools/audit_do_resources.py` 通过；机器清单在 `engineering/do_resource_manifest.json`。
- v3.4.3 已在项目隔离的 Arduino Mega 2560 工具链编译通过：Flash 43,198 B（17%），RAM 1,516 B（18%）。
- 网站构建与2项渲染测试通过，并已在 Chrome 打开 `http://localhost:3001/`。
- Blender 5.1.2 已在本机打开唯一活动主工程 `blender/output/BB8_1to1_screen_referenced.blend`；历史阶段检查点尚未删除，因为用户新增“只保留一个 Blender 工程”涉及不可逆清理，等待明确确认。

## 阶段 9：电影参考外观拓扑与可执行网站（2026-07-12）

- 主工程仍只有一个当前编辑源：`blender/output/BB8_1to1_screen_referenced.blend`。本阶段覆盖保存且关闭 Blender 自动 `.blend1` 版本生成，没有新增检查点工程。
- 身体六个主面板改为半角 35° 的球面区域，方向固定为 P1前、P2右、P3底、P4顶、P5左、P6后；环型数量冻结为 R1×3、R2×2、R3×1。
- 新增八个角区拓扑 T1a、T1b、T2、T3、T4、T5、T6、T7，以及六个面板的蓝/红/黄灯位审计。
- 头部增加 PSI 状态灯和长短两类天线元数据；主尺寸保持身体 Ø508 mm、头部 Ø295 mm、无天线高度 673 mm。
- Blender 后台关闭重开审计通过：261 个对象，其中 88 个内部机构对象；主工程 SHA-256 为 `a15c2518e8fbc4efd92c2b1ed67fca85832a7771abf83f91b0787d8501786835`。
- 三视图、STL 和 GLB 已从新主工程重新导出。网站装配区由 5 个概念步骤扩展为 24 个可验收步骤，包含零件、工具、动作、安全提示和本机进度记忆。
- 外观依据与未完成边界见 `docs/BB8_阶段8_外观拓扑与尺寸依据.md`；第三方权利边界见根目录 `NOTICE.md`。
- 仍存在 7 个历史 `.blend` 检查点、1 个 Blender 自动备份和 1 个网站下载副本。清理这些文件属于不可逆删除，必须等待用户明确确认；在确认前网站的 Blender 下载副本保持旧版并应视为暂停发布。

### 阶段 9.1 校对修正

- 逐页放大校对 Builders Club V3.1 后，修正了此前错误的环型对应：P1=R3，P2/P3=R2，P4/P5/P6=R1。
- 将六块面板共用的六辐图案替换为四桥结构；P1/P2/P5/P6 为对角桥，P3/P4 为正交桥。
- 六块面板分别增加视觉描摹的灰色弧段、肋条与灯舱，并写入独立 `pattern_variant` 和近似精度元数据；精确尺寸仍不能冒充官方 CAD。
- 新后台重开审计通过：265 个对象、88 个内部对象；加入程序化白色/橙色磨损材质后的主工程 SHA-256 为 `4df861cc3d8ee11e7cc8723c7791e3bf5a1b6a41bcf54e56abbb6fbbfebdbf87`。
- 网站新增六章直达、当前步骤媒体、80–180% 缩放、步骤完成勾选与刷新恢复；未新增 3D 依赖。GLB 已有 198 节点、194 网格和5条动画，正式节点级爆炸查看器仍需用户明确允许新增 `three` 运行依赖。

### 阶段 9.2 D-O 采购门控与三视图一致性

- 新增 `engineering/do_self_build_bom.csv`：24 项零件/子系统按可采购、冲突暂缓、负载未知、需工程设计和本地已就绪分类；不把来源示例值冒充最终选型。
- 新增 `docs/DO_自组采购与调试路线.md`：把合法文件、供电、IMU、遥控、声音、舵机、电机、系留平衡、低速行驶和热耐久拆成 D01–D16 验收门。
- 明确暴露 Printed Droid 公开说明的驱动板冲突：仓库根 README 为一块 MDD10A，v3.4 README 为两块 MD10C；电机、减速比、四个舵机负载和峰值电流未冻结前暂缓采购。
- 发现合成尺寸三视图仍引用旧六辐渲染，新增 `tools/build_bb8_three_view_sheet.py` 从当前正/侧/后视图可重复重建；新图 SHA-256 为 `aaa8d6bace45ac64b161f77dfe2a9146e5cc42d634f1c78a2f54b7deef04cd17`。
- Blender 审计增加三视图新鲜度与网站副本字节一致性门；后台重开仍为 265 个对象、88 个内部对象、6 个主面板、8 个角区和 508/295/673 mm。
- D-O 资源审计、Mega v3.4.3 固件编译、6 项 BB-8 运动/物理校验、网站构建和2项渲染测试全部通过；lint 0错误、3个 `<img>` 性能警告。
- 当前 Blender GUI 仍是带 `*` 的未保存旧内存状态，不能保存覆盖新主工程，也不能未经确认丢弃。生产构建把网站 `.blend` 副本复制进 `dist`，因此当前除主工程外共有10个历史/备份/网站/构建 `.blend` 副本；不可逆删除以及新增 `three` 依赖继续等待用户明确确认。

### 阶段 9.3 头部轮廓、670 mm 高度与装配网站实机验收

- StarWars.com 官方总高 0.67 m 与社区摄影测量的身体 Ø508 mm、头部 Ø295 × 197 mm 结合；头部轮廓下缘设为 `z=219 mm`，与球体上缘形成35 mm轮廓交叠，无天线几何总高精确为670 mm。
- 头壳重建为20 mm下锥、31 mm最大直径围带和椭圆半穹顶；删除四块错误的大圆橙板，增加11块下围带橙色分段、两道深色条带、细橙上缘、5块顶部石墨板、侧后维护板和缩短天线。
- 后台重开审计通过：292个对象、88个内部对象、6个主面板、8个角区、R1/R2/R3=3/2/1；主工程 SHA-256 为 `c4dd9fbd9a6f931992797ecbfa96d5a3559686047a40362821e7706e4b236ff0`。
- 最新三视图尺寸图为2728×1180，SHA-256 `09f9e155b7489bea25c5da63023390c6e0219f924684368010bc677294bfeac4`；GLB SHA-256 `bbf5ae88e22e5c8e96b4c54cbd87a33e950e7ee7ae2f582d8b89c6aabd55586c`。
- 装配网站改为每阶段2–3张正/侧/后/内部视图，分离“当前位置”和“实际完成率”，增加原生大图对话框；Chrome实机验证切换、弹窗、A01完成率1/24和本机存储后已清空测试状态。
- `npm test` 构建和2项HTML回归测试通过；lint 0错误、4个原生`<img>`性能警告。全仓 `tsc --noEmit`仍因既有Cloudflare全局类型声明缺失失败，不是本轮页面类型错误的充分证明，后续需补正式类型环境。
- 运动学、解析物理、多体/结构/电热、90°差速转弯、电机候选、磁耦合、D-O资源审计和Mega 2560固件编译全部重新通过；低电量峰值扭矩仍必须降额，磁体实际拉脱力仍需台架测量。
- GUI旧内存态已无损另存为 `blender/checkpoints/BB8_stage08_unsaved_gui_20260712_183729.blend`（SHA-256 `feae71f106221d76f751a086764a18efb1d146b19a03292d65c5384a449a375f`），随后在同一PID 87812内打开最新主工程；当前窗口无星号且只有1个Blender GUI进程。
- 当前共有11个 `.blend` 文件：8个追加式阶段检查点、1个主工程、2个未在页面链接的旧网站/构建副本。任何删除仍属于不可逆清理，未执行。

## 阶段 10：编码器 / IMU 闭环运动与失效停车（2026-07-12 19:03）

- `firmware/controller_core.*` 新增左右编码器轮速PI、IMU偏航率修正、运动传感器新鲜度和IMU/编码器一致性门槛；锁存故障由5类增加到7类。
- `tests/closed_loop_sim_test.cpp` 直接复用生产C++控制核心，以200 Hz模拟电机惯性、滚阻死区、编码器量化、电池压降、热模型和双轮位姿。
- 确定性场景通过：0.30 m/s巡航段RMS误差0.00772 m/s，转角91.20°；0.20 m/s重新起步后注入IMU过期，当前周期PWM归零，0.8 s后速度0.00224 m/s。
- 完整遥测保存为 `engineering/closed_loop_telemetry.csv`，报告为 `docs/BB8_阶段10_闭环运动仿真.md`；网站提供两者下载。
- ESP32适配器现在启用`require_motion_feedback`，但在真实IMU/编码器适配落地前显式保持新鲜度为false，因此硬件EN维持关闭，不能误把仿真PASS当作可落地运行许可。
- 本阶段未修改Blender几何；主工程仍为阶段9.3文件，后台重开审计和唯一GUI进程约束将在完整回归中复核。

## 阶段 11：ESP32 编码器与 MPU6050 适配（2026-07-12 19:18）

- 新增 `firmware/sensor_math.*` 与 `tests/sensor_math_test.cpp`，独立验证正反正交解码、无效跳变拒绝、轮速换算、MPU6050陀螺比例、倾角、重力范数和编码器750 ms响应超时。
- ESP32-S3适配器新增GPIO 10–13双编码器四边沿CHANGE中断、原子计数快照、96 mm轮径速度换算和α=0.20低通。
- 编码器每轮计数默认0且不持久化；必须每次上电发送`E <CPR> <左方向> <右方向>`。有运动需求但无脉冲时锁存停机。
- 新增GPIO 17/18 MPU6050 400 kHz I²C适配、0x68/0x69探测、±4g/±500°/s、42 Hz DLPF、400样本静止零偏和30 ms新鲜度门槛。
- Arduino-ESP32 3.3.10 / Generic ESP32-S3编译通过：程序367791 bytes（28%），RAM24636 bytes（7%）。
- 报告保存为 `docs/BB8_阶段11_ESP32传感器适配.md`，机器合同为 `engineering/sensor_adapter_contract.json`；实体板、传感器、编码器、电机和电流保护仍未接入验证。
- 完整回归通过：网站渲染、Pages 54文件审计、C++控制/传感器单测、闭环仿真、全部工程计算和D-O资源审计均为PASS；Blender主工程后台重开仍为292个对象/88个内部对象，GUI仅保留1个进程且窗口无未保存星号。

## 阶段 12：双 INA226 电流保护与堵转回放（2026-07-12 19:30）

- 新增 `firmware/power_safety.*`，只接受每次上电显式输入的瞬时电流、堵转电流和持续时间；未配置时拒动。
- ESP32-S3适配新增0x40/0x41双INA226、2 mΩ Kelvin分流合同、1 mA LSB、`0x0A00`校准、20 ms新鲜度和200 ms寄存器回读。
- 双ALERT开漏并联到GPIO14，并明确要求外部门同时直接拉低驱动EN；仅读GPIO不冒充硬件限流。
- 控制核心新增电流传感器过期、硬件ALERT、测量过流和持续堵转4类锁存，总计11类。
- 5 ms确定性回放覆盖同帧过流、0.300 s堵转、传感器过期和硬件告警；记录为 `engineering/power_safety_replay.csv`。
- Generic ESP32-S3实际编译通过：程序369971 bytes（28%），RAM24676 bytes（7%）。实体分流、限流、堵转、保险丝与热试验仍为NOT_RUN。

## 阶段 13：电流保护硬件进入内部模型（2026-07-12 19:54）

- 电子托盘新增双34 × 22 × 1.6 mm INA226包络、双12 × 5 × 3 mm/2 mΩ四线分流器、6个3 mm高M2.5支柱和28 × 14 × 1.6 mm独立ALERT→EN门板。
- 新增11条保护链线束：高侧输入2、监测后输出2、Kelvin采样4、开漏ALERT 2、失效低电平EN 1；随内车继承-4°到+4°俯仰动画。
- 内部对象由88增至110，总对象由292增至314；508/295/670 mm、6个主面板、8个角区、R1/R2/R3=3/2/1和原机械审计均保持PASS。
- 主工程、阶段13 v3检查点、内部四视图、内部STL、动画GLB和110件CSV装配清单已重建；v1/v2修正前检查点不删除并在检查点README中明确标为被取代。
- `physical_test_status`仍强制为`NOT_RUN`；真实四线焊点、ALERT断MCU、分流器脉冲温升、架空堵转、保险丝配合和封壳热平衡尚未执行。

## 阶段 14：质量/质心闭环与英文网站（2026-07-12 20:20）

- 新增17组最小/名义/最大质量账本、质心与三轴惯量计算，并穷举131072个最小/最大质量角点组合；名义8.463 kg、质心z=-56.2 mm，最不利角点z=-27.7 mm。
- 取消未经证明的110 mm偏置作为设计事实；若在z=-220 mm附近强求该偏置还需约4.14 kg，无法保持当前驱动余量。
- Blender新增120 × 70 × 24 mm、名义1.50 kg密封钢配重盒、中央挂板、双束带与4枚M5防松紧固件，以及名义/旧假设两个工程标记。
- 后台关闭重开审计通过：324个总对象、120个内部对象，其中118个制造对象进入STL/CSV，2个工程标记被导出脚本明确排除；主工程SHA-256为`291c80fa1ef2399459f78693f42f3d8b9cd7eeaf4a2b5f633d9cc59ffa0b94f9`。
- 按8.463 kg名义质量重跑解析物理：0.70 m/s²设计点每台电机需求0.299 N·m，0.6 N·m连续额定余量2.01×；真实称重、质心、结构、热与带电台架仍为`NOT_RUN`。
- 新增独立英文站入口`/en/`，完整包含24步装配、BB-8阶段14证据、D-O资源/许可边界、下载和中英文切换；与中文站共用同一批模型与校验文件。

## 阶段 15：驱动电源、硬件急停与动态坡道包络（2026-07-12 20:40）

- 现有阶段13只有双INA226、Kelvin分流与ALERT→EN门，没有电机驱动器实体包络，也没有从电池到驱动母线的完整去能链；阶段15补齐30个内部对象。
- 新增左右52 × 34 × 16 mm通用驱动安装包络、双散热器、8个M3支柱、主保险丝、常开接触器、双通道常闭急停接收器、安全继电器、维护断电和有线系留急停插口。型号、电流、保险丝和直流分断额定保持`NOT_FROZEN/TBD`。
- 主电源路径显式为电池正极→维护断电→保险丝→常开接触器→左右驱动器→电机；安全路径显式为急停A/B、接触器反馈和左右驱动EN。无线急停不能单独通过首轮验收。
- 新增阶段15解析验证器与136行坡度/加速度扫描。3°、0.20 m/s²、0.30 m/s、0.80 m转弯半径设计点为8.68 N推进力、0.289 N·m/电机、2.07×连续扭矩裕量、4.22°合成倾角；2×裕量下0加速度坡度上限约4.50°。
- 明确`unpowered_slope_hold=NOT_PROVIDED`：没有机械驻车制动，断电后不能在坡道保持位置。全部物理电流、热、牵引、分断、停止距离和坡道试验仍为`NOT_RUN`。
- 主工程与独立检查点保存后后台重开审计通过：354个总对象、150个内部对象，其中147个制造对象进入STL/CSV、3个工程标记被排除。主工程SHA-256为`7be78385f84064c63cc1882c0f6c008d6cc2ffdc1ff3ea07031745ee9b507d07`。
- 中英文网站同步阶段15结构、稳定性证据、下载与24步验收流程；英文站仍位于`/en/`。

## 阶段 16：真机遥测与不可伪造的物理验收门（2026-07-12 21:02）

- 新增 `engineering/commissioning_test_plan.json`，把真实运行拆成19个强制门：质量/质心、40 N磁头、电气去能、INA226与编码器标定、架空/堵转、开壳/封壳热、直行/转弯/急停/3°坡道、故障停车、再生母线、20次维护和10分钟综合运行。
- 新增 `engineering/commissioning_evidence.json` 真实硬件模板与 `tools/verify_commissioning_evidence.py`；PASS必须有实测数值、允许类型的真实相对路径和匹配SHA-256。当前19项均为`NOT_RUN`，结果强制为`HOLD_PHYSICAL_TESTS_NOT_RUN`。
- 新增 `tools/parse_bb8_telemetry.py`；ESP32每200 ms输出带`t_ms`的21个固定字段，解析器拒绝缺字段、非有限值和不递增时间。测试夹具覆盖正常解析、坏格式、伪造PASS拒绝与仅限单测的合成PASS。
- Stage16遥测固件用Arduino-ESP32 3.3.10 / Generic ESP32-S3重新编译通过：程序370095 bytes（28%），全局变量24676 bytes（7%）。编译仍不代表开发板上传或带电试验。
- 中英文网站新增阶段16报告、19项矩阵、证据模板和当前HOLD结果下载；24步装配尾段现直接引用对应物理测试ID。
- 本阶段不修改Blender几何、不新增`.blend`检查点；继续使用唯一活动主工程 `blender/output/BB8_1to1_screen_referenced.blend`。

## 阶段 17：官方数据表器件候选与采购冻结门（2026-07-12 21:30）

- 新增 `engineering/power_component_candidates.json` 与验证器，把MDD20A、30 A Littelfuse MIDI、Albright SW60和Molicel P28A 4S2P的官方额定、解析裕量、未知项和采购门分开记录；15项目录额定检查全部通过。
- MDD20A相对5.5 A电机额定的连续裕量3.64×，相对10.5 A/路解析峰值的目录峰值裕量5.71×；但它没有独立EN，PWM低为制动，且官方资料未冻结本应用再生路径，因此不能作为已放行驱动器。
- 暂定30 A MIDI保险丝仍需实际堵转波形、线径、温度和I²t配合；SW60要求辅助反馈和12 V连续线圈，普通二极管35 ms典型释放超过20 ms去能合同。
- P28A 4S2P只作为专业电池包候选；未找到已冻结的紧凑4S BMS。EMUS BMS mini因官方手册规定5–16串而明确淘汰。
- 当前机器结果为 `HOLD_COMPONENT_FREEZE_MEASUREMENTS_REQUIRED`；没有采购、成包、上电或真机测试。MDD20A的88.90 × 78.74 mm官方外形大于现有通用包络，本阶段不修改唯一Blender主工程，也不新增`.blend`副本。

## 阶段 18：模块化驱动电源舱解析布局与主模型写入（2026-07-13）

- 对唯一主工程做只读布局基线提取，记录了150个内部对象以及电池、电机、驱动轮、配重盒、桅杆和四只稳定臂的父坐标包络；源GUI当时存在未保存状态，因此基线明确标记 `source_saved_state=false`。
- 新增8个候选模块的机器可读布局：REC Active BMS 4S、MDD20A、SW60、MIDI保险丝服务包络、独立双通道门板、外置BMS分流器、安全继电器和急停接收器。
- 解析验证通过：最小球壳余量27.643 mm、候选件间隙7.500 mm、与既有机构间隙6.000 mm；12项实物尺寸、接口、散热、线束和维护验证仍为未通过，整体状态保持 `HOLD_PHYSICAL_FIT_AND_INTERFACE_VALIDATION_REQUIRED`。
- 用户明确确认“丢弃”后，在唯一Blender进程内重开磁盘主工程，执行阶段18几何写入、四张内部渲染、覆盖保存与再次重开审计；没有创建新的`.blend`副本或自动版本文件。
- 首次审计识别出AMPSEAL候选接口误计为第五个壳体维护连接器；生成器改为独立候选接口契约并增加检修前断开要求，同时让应用脚本显式重载Blender缓存模块。最终审计PASS。
- 最终主工程SHA-256为`3b774f3e02c89e15922aac48629a43d4765d37078acad88ccf34f6316827d5c3`；对象计数为363总对象、159内部对象、150制造对象、9工程标记和39阶段18对象。物理试装、上电与真机状态仍为`NOT_RUN`。
- 重导出150项装配清单、内部STL、动画GLB、机构图和内部正/侧/俯三视图；中英文报告与网站改为“Stage 18 applied + reopen audited”，英文站继续使用 `/en/`。

## 阶段 19：独立双许可 PWM 门预 CAD 设计（2026-07-13）

- 用厂商一手资料冻结预CAD电气合同：两路VO617A-4把12.0–16.8 V上电许可隔离到3.3 V，三片SN74LVC2G08依次门控SAFE_A、SAFE_B和双INA226开漏`ALERT_N`；MDD20A必须使用sign-magnitude模式。
- 64组输入组合穷举通过；SAFE_A、SAFE_B、ALERT_N、3.3 V掉电任一失效都将左右PWM拉低，MCU两路PWM卡高也不能越过任一许可级。
- 2.00 kΩ输入电阻解析为12.0 V时5.175 mA、16.8 V时7.900 mA，0.5 W电阻最坏功耗0.12482 W、降额4.006×；光耦发射极高电平模型2.9 V高于LVC的2.0 V门槛。
- 新增机器合同、64行真值表、预选BOM、引脚网表、验证器、4项单元测试、50 × 35 × 1.6 mm OpenSCAD板框与中英文报告。OpenSCAD 2021.01无头STL导出在限定时间内未完成，因此没有虚构STL。
- 在唯一Blender 5.1.2实例内把23个板件/器件包络写为`non_fabrication_reference`，覆盖保存同一主工程；关闭后重新打开审计通过，确认386个总对象、182个内部对象、150个制造对象、9个工程标记和23个阶段19参考对象。
- 当前主工程SHA-256为`ecd9a8b02db7c0b253c06005aaf16e7a8bf10147f8adec9c8900415e18b38af4`；已重导出150项制造清单、内部STL、动画GLB、机构图和内部正/侧/俯三视图，并发布机器可读的重开/哈希证据。
- 同步修正E02实体门：分别验证SAFE_A、SAFE_B、ALERT_N、3.3 V掉电和MCU停止，左右PWM必须在20 ms内拉低；安全继电器和常开接触器仍负责真正母线去能。
- 当前结果为`HOLD_PCB_CAD_BENCH_AND_SAFETY_VALIDATION_REQUIRED`；没有KiCad原理图、ERC/DRC、Gerber、实装板、示波器、温度、EMC或真机测试，物理状态继续`NOT_RUN`。

## 阶段 20：D-O 外部模型候选与许可证分层（2026-07-15）

- 重新核对公开模型入口，不再使用“网上没有免费 D-O 模型”的过宽结论；机器清单新增 `external_model_candidates` 六条记录，明确区分可动开发版、静态模型、关节展示/改装模型和未核验线索。
- Thingiverse `Denton V1` 页面级元数据标注 CC BY 4.0，并写明有分组件 STL 与 3D PDF；同页仍标注 WIP、头部缺失、STEP 待后续。页面还说明基础 CAD 由 Michael Baddeley 私下提供，因此压缩包内容和衍生再许可权都保持 `HOLD_INCOMPLETE_HEAD_ARCHIVE_AND_PROVENANCE_REVIEW`，未下载或镜像文件。
- Cults `JRIZZ D-O` 页面列出 Fusion 360 F3Z、机器人端/遥控端 Arduino 草图、STL 和可动硬件架构，是最接近“机械 + 控制”的整合候选；但它是付费 `CULTS - Private Use` 开发版，当前保持 `PAID_PRIVATE_USE_NOT_ACQUIRED_OR_VERIFIED`。没有购买、接受条款或抓取数字文件。
- Printables `WF3D` 版本核验为约300 mm、32文件、CC BY-NC-SA 4.0 静态模型；`Home Decor` 版本为11文件、CC BY-NC 4.0 WIP remix。Gambody 页面列出116个STL和518 mm life-size关节版，但没有控制源码、电气设计或平衡算法；三者都不能冒充可运行整机。
- MakerWorld 23859 在本轮被 Cloudflare 阻断，文件、作者和许可保持 `UNVERIFIED`，不会列为可用开源资源。
- 中英文网站、三份 D-O 文档、采购门控 BOM、NOTICE、测试和公开下载镜像同步更新；`npm test`、D-O 8项单元测试、Pages 101文件审计和 lint 0错误全部通过，lint 保留8个既有 `<img>` 性能警告。
- 唯一 Blender 主工程未写入、未保存、未关闭；SHA-256 仍为 `ecd9a8b02db7c0b253c06005aaf16e7a8bf10147f8adec9c8900415e18b38af4`，电脑上仍只有 PID 76843 一个 Blender 进程。BB-8 物理状态继续为0/19，D-O付费候选与真机装配仍未放行。

## 阶段 21：D-O v3.4.3 D22–D25 安全引脚变体（2026-07-15）

- 重新审计固定上游源码，确认四路舵机为 D0/D1/D5/D6，而 `Serial.begin(9600)` 同时占用 D0/RX0 与 D1/TX0；原始源码 SHA-256 为 `6cb3ce0d96c83724aaf9170eaef592c3d7cc866b9da66819db9e9f3fe134a707`。
- 新增 `tools/build_do_safe_pin_variant.py`。工具只接受固定提交 `e90aacdbe26a62fd4f0229d5504a3f2f3c409055` 与上述原始哈希，检查目标引脚未被其他数值信号常量占用后，将主杆/头1/头2/头3舵机统一转换为 D22/D23/D24/D25。
- 转换后源码 SHA-256 为 `f858c4856adf599617875bc6be31224c174ecaf1a7aac98b1f153adca4a91441`；Arduino Mega 2560 实编译通过，Flash 43,198 / 253,952 B（17%），RAM 1,516 / 8,192 B（18%）。修改后第三方源码和二进制不进入公开仓库或 Pages。
- 新增 `engineering/do_safe_pin_variant_compile.json` 与 `engineering/do_safe_pin_variant_wiring.csv`，公开区只镜像本项目生成的证据、线束合同和转换工具。D031 前进为 `SOFTWARE_REMAP_READY_HOLD_PHYSICAL_CONTINUITY`，D032 前进为 `VARIANT_WIRING_GENERATED_HOLD_CONTINUITY`。
- 软件级 D0/D1 冲突已在该变体中消除，但实体逐网导通、USB上传/复位、9600 baud菜单、D22–D25四路脉宽、失效保护与舵机电源均为 `NOT_RUN`；`actuator_power_release=false`、`flash_release=false`。
- 本阶段未修改、保存或关闭 Blender 主工程；继续保留单一 Blender 进程和阶段19磁盘哈希。BB-8实体19项门仍为0/19，阶段19 KiCad/ERC/台架门也未解除。

## 阶段 22：阶段19正式 KiCad 原理图与 ERC 交叉审计（2026-07-15）

- 使用KiCad 10.0.4确定性生成正式`.kicad_sch`、项目本地符号库和可打开的`.kicad_pro`；原理图包含J1–J5、U1–U5、R1–R13、C1–C3、D1–D2与TP1–TP6，共34个器件引用。
- `kicad-cli sch erc --severity-all --exit-code-violations`实跑为0项违规；同时成功导出KiCad XML网表、34引用BOM和一页A4原理图PDF。PDF经180 dpi渲染逐页检查，标题栏、安全输入、三级许可链、偏置/去耦与测试点无实质重叠。
- 新增`tools/verify_stage19_kicad.py`：重新生成并逐字节比对原理图/符号库，实跑ERC及导出，再把34个器件引用、91条规范引脚连接和21个网络与`stage19_gate_netlist.csv`交叉审计；当前全部检查通过。
- 交叉审计纠正CSV中的D1/D2脚位语义：KiCad `Device:D`的1脚为阴极K、2脚为阳极A；正式原理图本身连接正确。
- 中英文网站新增完整KiCad工程ZIP、原理图PDF、ERC JSON、XML网表、KiCad BOM、交叉审计结果、生成器和验证器下载；制造边界更新为“原理图/ERC通过，但无独立同行复核、PCB/DRC、Gerber、实装板或台架波形”。
- 未修改、保存或关闭唯一Blender主工程；磁盘SHA-256继续为`ecd9a8b02db7c0b253c06005aaf16e7a8bf10147f8adec9c8900415e18b38af4`。阶段19总体仍为`HOLD_PCB_CAD_BENCH_AND_SAFETY_VALIDATION_REQUIRED`，实体19项门仍为0/19。

## 阶段 23：阶段19两层布线 PCB、DRC 与公开证据链（2026-07-15）

- 新增可确定性生成的`stage19_dual_permissive_gate.kicad_pcb`：50 × 35 mm、2层、38个封装（34个电气器件加4个M3非金属化安装孔）、21个命名网络、1614段走线、54个过孔，以及F.Cu 3V3/B.Cu GND铜区。
- 四个Ø3.2 mm安装孔中心严格位于板框原点的`(3,3)`、`(47,3)`、`(3,32)`、`(47,32)` mm；34个器件引用、91条规范引脚连接和21个网络与原理图合同一致。
- `tools/verify_stage19_kicad_pcb.py`会临时重生成PCB，比较不依赖UUID的结构清单，并分别对跟踪板和重生成板运行KiCad 10.0.4 DRC；两者均为0项违规、0个未连接项，结构SHA-256一致。
- 新增PCB正面、背面和等距3D复核图；中英文网站与下载区同步提供`.kicad_pcb`、DRC JSON、PCB验证JSON和生成/验证工具。没有生成或发布Gerber、钻孔制造包。
- `pcb_routed_and_drc_passed=true`只表示参考设计的机器检查通过；独立原理图/布局同行复核、Gerber/钻孔发布复核、实装板导通、上电、20 ms示波器、温升、EMC与整机物理调试仍为未通过，因此制造发布保持`NOT_RELEASED_PEER_REVIEW_GERBER_AND_PHYSICAL_VALIDATION_REQUIRED`，总体继续HOLD，实体门仍为0/19。
- 唯一Blender主工程未修改、保存或关闭；磁盘SHA-256继续为`ecd9a8b02db7c0b253c06005aaf16e7a8bf10147f8adec9c8900415e18b38af4`，电脑上仍只保留一个Blender进程。

## BB-8 工程阶段 21：切向轮轴、冠形轮与径向预压滑台（2026-07-15）

- 重新检查现有96 × 26 mm驱动轮，确认它是轴向沿X的有限圆柱，不是旧注释所称的冠形轮。旧重开审计用“轮心半径 + 最大尺寸/2”把圆柱当成96 mm球体，支撑半径高估5.072 mm；精确有限圆柱包络实际离254 mm内壳5.070 mm。
- 当前轮轴相对局部球壳切平面偏48.800°，名义接触会落向轮缘并产生擦滑风险。`blender/audit_bb8.py`已改成逐网格顶点计算真实支撑半径；历史Stage-19驱动轮接触通过结论被Stage21明确取代，稳定球仍按各自真实网格检查。
- 选定`TANGENT_AXIS_PARALLEL_BELT_RADIAL_SLIDE_V1`参考架构：轮轴切向，IG42电机轴与轮轴平行并径向内移80 mm；24T/24T、5 mm节距、80 mm轴距解析得到280 mm/56齿候选带，电机包络仍有92.845 mm名义壳体余量。
- 26 mm宽轮在254 mm内球面至少需0.333 mm边缘降高；参考轮采用0.750 mm抛物线冠形，轮缘解析余量0.417 mm。滑台总行程12 mm，名义点向内3 mm、向外9 mm，覆盖阶段20的5.5 mm公差预算后余3.5 mm。
- M6×1只用于找接触，最终必须用测力夹具把每侧设到60–100 N、目标80 N、左右差不超过10 N。1.2 N·m峰值、3×冲击、2×防滑系数和摩擦系数0.15下，滑台最低夹紧需求为1000 N/侧；该数值不是螺栓等级或预紧通过证明。
- 新增机器合同、8项单元测试、验证器、0.5 mm调节扫描、12项BOM、中英文报告、OpenSCAD源、精确DXF、冠形轮STL、装配包络STL和工程复核图。本机OpenSCAD只有失效软链接，未擅自安装；无依赖回退导出器生成并哈希所有公开CAD参考文件，板件STL明确标为无孔包络，孔槽以DXF为准。
- 轮心距310 mm不等于内球面接触点间距382.233 mm；后者不能直接写入固件，必须在安装后用实车偏航响应辨识有效轮距。
- 当前打开的用户修改版Blender主工程未被保存、覆盖或纳入本阶段提交，Stage21装机干涉仍为`NOT_RUN`。总体保持`HOLD_PHYSICAL_CONTACT_BELT_BEARING_AND_CHASSIS_INTEGRATION_REQUIRED`，13项集成/实物门与19项整机物理门均未关闭。

## BB-8 工程阶段 22：标准同步带、双轴承键轴与底盘接口（2026-07-17）

- Gates 2025工业传动目录的15 mm宽5MGT标准长度从300 mm起，阶段21的`5M-280-15 / 280 mm / 56齿`不在该标准库存表内。阶段22改用官方产品`5MGT-300-15`、产品号`92706002`、300 mm节线、60齿和15 mm宽。
- 两只24T等径5MGT带轮改为90 mm轴距后，闭式节线精确为300.0 mm，传动比保持1:1；24齿高于Gates的18齿最小建议。电机位提供4 mm总张紧调节，但额定功率和安装张力仍需DesignFlex或供应商计算。
- 每侧参考轮组采用两只6001轴承、38 mm轴承中心跨距和14.5 mm带轮悬臂。以SKF W 6001-2RS1的4.42 kN动额定、2.36 kN静额定和16000 r/min作评级下限，3×冲击扭矩加每跨80 N预紧上界时，最重外侧等效载荷532.8 N、静安全4.43、1000 r/min解析L10为9516 h。
- 12 mm键轴在3.6 N·m冲击扭矩、带轮悬臂和100 N轮压下，乘2.5键槽系数后的von Mises为100.2 MPa；要求材料证书屈服强度至少400 MPa，解析安全系数3.99。4×4×20 mm平键解析通过，但7.2 N·m无滑移、无永久变形的实物扭矩证明仍未执行。
- 每侧底盘接口用两根6 mm定位销、四颗M6夹紧和硬限位形成不依赖摩擦的正向载荷路径；1000 N设计载荷下定位销单剪17.7 MPa、6 mm板孔挤压13.9 MPa、边缘撕裂4.6 MPa。
- 新增机器合同、12项单元测试、验证器、载荷工况CSV、BOM、中英文报告、OpenSCAD源、两份DXF、键轴/装配包络STL、SHA-256 CAD清单和工程复核图；中英文网站同步提供全部参考下载，并在首屏和页脚显示公开GitHub仓库地址。
- 网站新增横版Open Graph分享图和绝对GitHub Pages元数据。分享图由一次安全重试后的通用球形机器人工程视觉生成，不替代三视图、Blender或解析证据。
- 当前用户修改版`blender/output/BB8_1to1_screen_referenced.blend`保持原样，Stage22没有保存、覆盖或重新打开它。总体为`HOLD_SUPPLIER_FITS_TENSION_TORQUE_PROOF_AND_PHYSICAL_INTEGRATION_REQUIRED`；13项供应商、制造、干涉和真机门仍未关闭。

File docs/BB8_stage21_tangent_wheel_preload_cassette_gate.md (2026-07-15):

# BB-8 Stage 21: Tangent Wheel and Preload Cassette Gate

> **HOLD_PHYSICAL_CONTACT_BELT_BEARING_AND_CHASSIS_INTEGRATION_REQUIRED**. Exact geometry and reference packaging screens pass, but the open Blender master was not modified and no fabricated contact evidence exists.

## Superseding the old wheel-contact result

- The current 96 × 26 mm powered wheel is a finite cylinder. The old centre-radius-plus-48 mm audit treated it as a sphere and overstates its support by **5.072 mm**.
- The exact finite-cylinder support leaves at least **5.070 mm** to the inner shell, so the historical powered-wheel contact pass is superseded.
- The current axle misses the local shell tangent plane by **48.800°**, driving contact toward the edge and creating scrub risk.

## Selected architecture: tangent axle plus parallel synchronous belt

- The wheel axle is tangent to the local shell. The parallel motor axis moves 80 mm radially inward and drives 1:1 by belt, avoiding direct tangent packaging of the 125.2 mm motor envelope.
- Equal 24T, 5 mm-pitch pulleys at 80 mm centre distance calculate to **280.0 mm / 56 teeth**, represented by a 5M-280-15 candidate. Supplier capacity, pretension and guarding remain open.
- The motor envelope support is 161.16 mm, leaving 92.84 mm nominal shell clearance. This is an envelope screen, not a current-chassis clash pass.

## Crown and radial setting

- A 26 mm-wide wheel needs at least **0.333 mm** edge drop in the 254 mm inner sphere. The reference uses a 0.750 mm parabolic crown and leaves **0.417 mm** analytical edge clearance.
- Total travel is **12.0 mm**: 3 mm inward and 9 mm outward from nominal contact. That covers the 5.5 mm Stage-20 stack with **3.5 mm** reserve.
- The M6×1 screw gives 1 mm per turn and 0.25 mm per quarter-turn. Turns only find contact; a force fixture must set 60–100 N per side, target 80 N, with no more than 10 N left-right mismatch before four M6 clamps are locked.
- The 9 mm outward reserve is not allowable tire compression. After contact, adjust by measured force only.

## Load and control gates

- 1.2 N·m gives 25.0 N at each wheel. With 3× shock, 2× slip factor and μ=0.15, the minimum clamp demand is **1000 N** total or 250 N per M6. This is demand only, not a bolt/preload pass.
- Ideal 12 mm shaft torsional shear demand is 10.61 MPa at 3× torque; keyway, material, hub and fatigue remain open.
- Wheel-centre track remains 310.0 mm, while nominal shell contact-patch spacing is **382.2 mm**, 72.2 mm above the firmware's current 310 mm parameter. Do not copy the analytical value into firmware; identify effective track from physical yaw response.

## Assembly sequence

1. Machine deburred fit-test plates from the reference DXF; dry-fit side plates, 6001 bearings, 12 mm shaft and wheel pulley.
2. Fit the motor pulley and candidate 5M-280-15 belt, then hand-turn one revolution to inspect tracking. Never power it without the guard.
3. Retract both slides to the inner stops, install in the shell, advance to first contact and use a force fixture—not turns—to set the 80 N target.
4. Lock four M6 clamps, remeasure preload and belt tracking, then run raised-wheel low-speed, E-stop and thermal tests.
5. Identify effective track from low-speed physical yaw data before changing the controller.

Open freeze gates: 13. Manufacturing release is false and all nineteen physical commissioning gates remain incomplete.

The machine contract, HOLD result, 0.5 mm adjustment sweep, BOM, OpenSCAD, DXF/STL and verifier are stored with the project.

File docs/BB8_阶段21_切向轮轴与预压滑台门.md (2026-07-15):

# BB-8 阶段 21：切向轮轴与预压滑台门

> **HOLD_PHYSICAL_CONTACT_BELT_BEARING_AND_CHASSIS_INTEGRATION_REQUIRED**。精确几何和参考包装筛查通过，但未改动当前打开的 Blender 主模型，也没有制造或真机接触证据。

## 纠正旧轮—壳接触结论

- 当前 96 × 26 mm 驱动轮是有限宽圆柱。旧审计用“轮心半径 + 48 mm”把它当成球，结果比真实包络高估 **5.072 mm**。
- 逐轴精确圆柱支撑函数给出的最小轮—壳间隙是 **5.070 mm**；旧 Stage-19 接触通过结论对驱动轮作废。
- 现有轮轴相对球壳切平面偏离 **48.800°**，会把接触推到轮缘并引入擦滑风险。

## 选定结构：切向轮轴 + 平行轴同步带

- 轮轴改为与球壳局部切平面平行；电机轴与轮轴平行，电机沿径向内移 80 mm，用 1:1 同步带传动，避免 125.2 mm 长电机直接沿切线撞壳。
- 24T / 24T、5 mm 节距、80 mm 轴距的闭式节线长度是 **280.0 mm / 56 齿**；候选为 5M-280-15。额定能力、预紧和防护罩仍需供应商与实物验证。
- 电机包络最外支撑半径 161.16 mm，名义球壳余量 92.84 mm；这只是解析包络，不是当前 Blender 车架的完整干涉检查。

## 冠形轮与径向调节

- 26 mm 宽轮在 254 mm 内球面上至少需要 **0.333 mm** 边缘降高；参考轮采用 0.750 mm 抛物线冠高，轮缘解析余量 **0.417 mm**。
- 滑台总行程 **12.0 mm**：名义接触点距内限位 3 mm，向内保留 3 mm，向外保留 9 mm；覆盖阶段20的5.5 mm公差预算后仍余 **3.5 mm**。
- M6×1 调节螺杆每圈 1 mm，四分之一圈 0.25 mm。圈数只用于找接触；最终必须用测力夹具把每侧预压调到 60–100 N、目标 80 N，左右差不超过 10 N，再锁紧 4 颗 M6。
- 禁止把 9 mm 外向余量当成轮胎压缩量；一旦接触，后续只按力值调整。

## 载荷与控制校准门

- 1.2 N·m 峰值对应每轮 25.0 N；3×冲击和2×防滑系数、摩擦系数0.15下，滑台最小总夹紧需求为 **1000 N**，四颗M6平均 250 N/颗。这里只给需求，不给螺栓强度或预紧通过结论。
- 12 mm 轮轴在3×扭矩下的理想圆轴扭转剪应力需求为 10.61 MPa；键槽、材料、疲劳和轮毂仍未冻结。
- 轮心距仍是 310.0 mm，但球壳名义接触点横向间距是 **382.2 mm**，比固件当前 310 mm 参数大 72.2 mm。球内多体转向不能靠这一个解析数直接改固件，必须用实车偏航响应重新辨识。

## 自组装顺序

1. 先用DXF加工样板并去毛刺，只做空载装配；确认两片侧板、6001轴承、12 mm轴和24T轮侧皮带轮同轴。
2. 安装电机侧24T皮带轮与5M-280-15候选带，手转一周检查跑偏；没有防护罩时不得通电。
3. 两侧滑台退到内限位，装入球壳后逐侧推进到首次接触；用测力夹具而不是圈数设置80 N目标。
4. 锁紧四颗M6后复测预压与皮带跑偏，再做架空低速旋转、急停和温升测试。
5. 最后用低速地面偏航数据重新辨识有效轮距；未经该步骤不得把解析接触距写入控制器。

开放冻结门：13 项；制造发布为否，19项整机物理调试仍未通过。

机器合同、HOLD结果、0.5 mm调节扫描、BOM、OpenSCAD、DXF/STL和验证器均随项目保存。

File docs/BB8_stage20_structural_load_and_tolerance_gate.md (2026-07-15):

# BB-8 Stage 20: Structural Load and Tolerance Gate

> **HOLD_JOINT_TOLERANCE_MATERIAL_AND_PHYSICAL_VALIDATION_REQUIRED**. Current digital geometry and closed-form screening pass, but manufacturing release remains false; material, joint, tolerance and physical evidence are open.

## Correcting the legacy geometry

- The current Stage-19 fabrication manifest contains a **Ø24 × 340 mm** magnetic-mast envelope.
- Stage 2 still analyses a **Ø12/Ø8 × 300 mm** aluminium tube, so that mechanical result is not current-model evidence.
- Stage 20 does not touch the open Blender session. It screens a Ø24/Ø20 × 340 mm tube candidate while keeping the bore, material lot and joints unfrozen.

## 2.5 g / 1.0 g analytical screening

| Load path | Analytical result | Evidence boundary |
|---|---:|---|
| Ø24/Ø20 mast candidate | 3.273 MPa, 0.154 mm tip deflection, 84.33× yield factor | No joints, welds, holes or strain data |
| Two Ø12/Ø8 brace candidates | 6.191 N each, 974.8× Euler factor | Pinned ends and bore are candidates |
| Two 380 × 18 × 12 mm rails | 22.814 MPa, 0.670 mm deflection, 12.10× yield factor | Simply supported symmetric sharing; joints omitted |
| 120 × 8 × 12 mm crossmember | 8.105 MPa, 0.024 mm deflection | One-quarter total-shock allocation only |
| 4 mm motor plate / 4×M4 PCD35 | 18.25 N resultant per M4 and 1.140 MPa plate-hole bearing demand | Demand only; M4 grade, preload, hole size and edge distance unfrozen |
| Eight nominal latches | 640 N, 3.08× total 2.5 g shock | 80 N per latch is unmeasured |

## Modal, fatigue and tolerance gates

- The unbraced-credit mast estimate is **40.47 Hz**, 9.79× the 248 rpm motor rotational frequency; hammer testing is still required.
- Ideal 6061-T6/T651 base-material fatigue screens are 29.64× for the mast and 4.25× for a rail. Welds, holes, surface condition and the real duty spectrum are excluded.
- The wheel-to-shell stack requires **5.5 mm** radial adjustment. The current digital geometry provides 0.0 mm, leaving a **5.5 mm** shortfall, so contact preload cannot be frozen.

## Material source and release boundary

Kaiser typical 6061-T6/T651 sheet/plate values—68.3 GPa elastic modulus, 276 MPa yield and 97 MPa reversed-stress fatigue endurance at 5×10^8 cycles—are used only for screening: https://online.kaiseraluminum.com/depot/PublicProductInformation/Document/1015/Kaiser_Aluminum_6061_Sheet_Coil_and_Plate.pdf. They are not certificates for purchased tube, bar, weld heat-affected zones or machined parts.

Open freeze gates: 15. Material certificates, joint details, fasteners, wheel preload adjustment, shell contact strength, strain/impact/modal/endurance work and all nineteen physical commissioning gates are required before fabrication release can be considered.

Machine result: `engineering/stage20_structural_load_results.json`; envelope sweep: `engineering/stage20_structural_load_sweep.csv`.

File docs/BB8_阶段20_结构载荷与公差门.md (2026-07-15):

# BB-8 阶段 20：结构载荷与公差门

> **HOLD_JOINT_TOLERANCE_MATERIAL_AND_PHYSICAL_VALIDATION_REQUIRED**。当前数字几何与闭式解析筛查通过，但制造发布仍为否；材料、连接、公差和真机证据均未完成。

## 首先纠正旧几何

- 当前 Stage-19 制造清单中的磁力桅杆包络是 **Ø24 × 340 mm**。
- 阶段 2 仍按 **Ø12/Ø8 × 300 mm** 铝管计算；该机械结论不再代表当前主模型。
- 阶段 20 不改动正在打开的 Blender 文件，而是把 Ø24/Ø20 × 340 mm 定义为待冻结的管材候选；内孔、材料批次和连接仍是开放门。

## 2.5 g / 1.0 g 解析筛查

| 路径 | 解析结果 | 证据边界 |
|---|---:|---|
| Ø24/Ø20 桅杆候选 | 3.273 MPa，挠度 0.154 mm，屈服裕量 84.33× | 无接头、焊缝、孔位与实测应变 |
| 两根 Ø12/Ø8 斜撑候选 | 单根 6.191 N，Euler 屈曲裕量 974.8× | 端部铰接和管内径只是候选 |
| 两根 380 × 18 × 12 mm 纵梁 | 22.814 MPa，挠度 0.670 mm，屈服裕量 12.10× | 简支、对称分载；连接未建模 |
| 120 × 8 × 12 mm 横梁 | 8.105 MPa，挠度 0.024 mm | 仅分配总冲击的四分之一 |
| 4 mm 电机面板 / 4×M4 PCD35 | 每颗 M4 合成需求 18.25 N，板孔承压需求 1.140 MPa | 只算需求；M4 等级、预紧、孔径和边距未冻结 |
| 8 个锁扣名义夹紧 | 640 N，对 2.5 g 总冲击比 3.08× | 80 N/个尚未实测 |

## 模态、疲劳与公差

- 无斜撑信用的桅杆一阶弯曲估算为 **40.47 Hz**，是 248 rpm 电机转频的 9.79×；仍需锤击模态试验。
- 理想 6061-T6/T651 基材疲劳筛查：桅杆 29.64×、纵梁 4.25×。这不覆盖焊缝、孔口、表面和真实载荷谱。
- 轮—壳接触公差预算要求 **5.5 mm** 径向调节，当前数字几何提供 0.0 mm，短缺 **5.5 mm**。因此接触预紧不能冻结。

## 材料来源与放行边界

Kaiser 6061-T6/T651 典型数据用于解析筛查：68.3 GPa 弹性模量、276 MPa 屈服强度和 97 MPa（5×10^8 次反向应力）疲劳耐久值。来源：https://online.kaiseraluminum.com/depot/PublicProductInformation/Document/1015/Kaiser_Aluminum_6061_Sheet_Coil_and_Plate.pdf。这些是典型板材数据，不是待购管材、棒材、焊接热影响区或加工件的材料证书。

未关闭冻结门：15 项。必须完成管材/板材证书、连接详图、紧固件、轮压调节、壳体接触强度、应变/冲击/模态/耐久和 19 项整机调试后，才可讨论制造放行。

机器可读结果：`engineering/stage20_structural_load_results.json`；载荷扫描：`engineering/stage20_structural_load_sweep.csv`。

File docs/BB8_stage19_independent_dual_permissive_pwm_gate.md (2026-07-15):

# BB-8 Stage 19: Independent dual-permissive PWM gate schematic and routed-PCB/DRC gate

> Conclusion: **all 64 Boolean combinations, input-current, logic-level, resistor-derating and 50 x 35 x 15 mm envelope checks pass. The deterministic KiCad 10 schematic has 0 ERC violations; a routed 50 x 35 mm two-layer PCB now has 0 DRC violations and 0 unconnected items. Its 34 electrical references, 91 canonical pin connections and 21 nets cross-audit through both schematic and PCB evidence. Independent schematic/layout peer review, Gerber/drill release review, assembled-board and oscilloscope evidence remain absent, so the result stays `HOLD_PCB_CAD_BENCH_AND_SAFETY_VALIDATION_REQUIRED`.**

## Purpose

Stage 17 established that MDD20A exposes PWM+DIR but no independent enable, and that PWM low is brake rather than electrical isolation. Stage 18 reserved a 50 x 35 x 15 mm gate-board volume. Stage 19 turns that placeholder into a machine-auditable schematic plus routed two-layer PCB/DRC reference design while retaining the safety relay and normally-open SW60-class contactor as the actual motor-bus isolation path.

## Three-permissive chain

Both motor channels implement:

`PWM_OUT = LOGIC_POWER_OK AND PWM_IN AND SAFE_A_OK AND SAFE_B_OK AND ALERT_N`

| Stage | Device | Function | Fail-low target |
| --- | --- | --- | --- |
| A/B inputs | 2 x Vishay VO617A-4 | Isolate 12.0–16.8 V energise-to-run loops into 3.3 V permissives | Removing either loop drops its permissive |
| Permissive A | TI SN74LVC2G08 U3 | Gate both PWM inputs with `SAFE_A_OK` | A alone blocks both PWM outputs |
| Permissive B | TI SN74LVC2G08 U4 | Gate both U3 outputs with `SAFE_B_OK` | B alone blocks both PWM outputs |
| Current alert | TI SN74LVC2G08 U5 | Gate both U4 outputs with dual-INA226 open-drain `ALERT_N` | Either hardware ALERT blocks both PWM outputs |
| Bus isolation | Safety relay + NO contactor | Remove the motor bus in parallel with the PWM gate | PWM low never substitutes for this layer |

`DIR_L/R` are direct pass-through signals, not safety signals. The design is therefore valid only for MDD20A sign-magnitude operation.

## Official data and calculations

- [TI SN74LVC2G08 data sheet](https://www.ti.com/lit/ds/symlink/sn74lvc2g08.pdf): `VIH >= 2.0 V` and `VIL <= 0.8 V` at 3.0–3.6 V; maximum 5.3 ns per gate at 3.3 V ±0.3 V and -40–125 °C; `Ioff` supports partial-power-down protection.
- [Vishay VO617A data sheet](https://www.vishay.com/docs/83430/vo617a.pdf): VO617A-4 CTR is 160–320% at `IF=5 mA`, `VCE=5 V`, 25 °C; maximum `VCE(sat)` is 0.4 V at `IF=5 mA`, `IC=1 mA`. The 25 µs saturated turn-off is typical, not a maximum bound.
- [Cytron MDD20A product page](https://sg.cytron.io/p-20amp-6v-30v-dc-motor-driver-2-channels): inputs accept 1.8/3.3/5/12 V logic and PWM up to 20 kHz.
- [JST XH official catalogue](https://www.jst-mfg.com/product/pdf/eng/eXH.pdf): 2.5 mm pitch; the standard top-entry series has 9.8 mm mounting height and a 3 A rating with AWG22.

At 12.0 V and the data-sheet 1.65 V forward-voltage upper point, the 2.00 kΩ input resistor gives 5.175 mA, reaching the 5 mA CTR test point. At 16.8 V and 1.0 V forward voltage it gives 7.900 mA. Worst resistor dissipation is 0.12482 W, so a 0.5 W part provides 4.006x derating. With the 0.4 V saturation limit, the emitter-follower high model is 2.9 V—above the 2.0 V LVC threshold—and its 4.7 kΩ load is about 0.617 mA, below the 1 mA saturation test current.

The three-package LVC chain has a 15.9 ns digital maximum. The optocoupler switching figure is typical only, so the complete 20 ms de-energise limit still requires oscilloscope evidence.

## Mechanical and manufacturing boundary

- PCB: 50 x 35 x 1.6 mm, two copper layers, with four Ø3.2 mm NPTH holes at (3,3), (47,3), (3,32) and (47,32) mm from the board origin. The PCB plus 9.8 mm JST XH envelope is 11.4 mm high. Including a 3.0 mm insulated mounting stack makes the installed height 14.4 mm, leaving only 0.6 mm inside the Stage-18 keepout; a purchased-sample fit check is mandatory.
- The OpenSCAD source contains only board, holes and component envelopes. It has no pads, copper, solder mask, silkscreen, creepage or cable-bend proof. The local OpenSCAD 2021.01 headless export did not complete within the bounded run, so Stage 19 does not claim an STL.
- The 23 Blender board/component envelopes are tagged `non_fabrication_reference`. They may appear in the GLB (with custom properties) and internal orthographic renders for design review, but they are excluded from the 150-part fabrication manifest and internal-mechanism STL.
- Those 23 references are now written into the sole master and have passed a close-and-reopen audit. Blender 5.1.2 reports 386 total objects, 182 internal objects, 150 fabrication objects, nine engineering markers and 23 Stage-19 reference objects. The master SHA-256 is `ecd9a8b02db7c0b253c06005aaf16e7a8bf10147f8adec9c8900415e18b38af4`; the 150-row manifest, internal STL, animated GLB and front/side/top internal views were re-exported.
- The formal `.kicad_sch` and `.kicad_pcb` are both generated deterministically. KiCad 10.0.4 reports 0 ERC violations, 0 PCB DRC violations and 0 unconnected items. A UUID-independent structural audit matches the tracked and regenerated boards, covering 34 electrical references, 91 canonical pin connections, 21 nets, 1,614 track segments, 54 vias and the F.Cu 3V3/B.Cu GND zones. There is still no independent schematic/layout peer review or Gerber/drill release. This stage does not authorise a PCB order.

## Released evidence

- [Machine contract](../engineering/stage19_dual_permissive_gate_contract.json)
- [64-row truth table](../engineering/stage19_gate_truth_table.csv)
- [Provisional BOM](../engineering/stage19_gate_bom.csv)
- [Pin netlist](../engineering/stage19_gate_netlist.csv)
- [Current HOLD result](../engineering/stage19_dual_permissive_gate_results.json)
- [Blender reopen audit and export hashes](../engineering/stage19_blender_reopen_audit.json)
- [Verifier](../tools/verify_dual_permissive_gate.py)
- [KiCad schematic](../hardware/stage19_dual_permissive_gate/stage19_dual_permissive_gate.kicad_sch)
- [KiCad ERC report](../engineering/stage19_kicad_erc.json)
- [KiCad connectivity export](../engineering/stage19_kicad_netlist.xml)
- [KiCad schematic verification](../engineering/stage19_kicad_verification.json)
- [KiCad schematic PDF](../output/pdf/BB8_stage19_dual_permissive_gate_schematic.pdf)
- [KiCad verifier](../tools/verify_stage19_kicad.py)
- [Routed KiCad PCB](../hardware/stage19_dual_permissive_gate/stage19_dual_permissive_gate.kicad_pcb)
- [Zero-violation PCB DRC report](../engineering/stage19_kicad_pcb_drc.json)
- [PCB structural/regeneration verification](../engineering/stage19_kicad_pcb_verification.json)
- [PCB generator](../tools/generate_stage19_kicad_pcb.py)
- [PCB verifier](../tools/verify_stage19_kicad_pcb.py)
- [PCB review-image exporter](../tools/export_stage19_kicad_pcb.py)
- [PCB isometric review render](../output/pcb/BB8_stage19_gate_pcb_isometric.png)
- [Hardware package notes](../hardware/stage19_dual_permissive_gate/README.md)

## Next non-skippable gates

1. Independently peer-review the captured KiCad schematic and safety assumptions.
2. Independently review the routed PCB isolation, mounting, polarity, test points and harness exits; the automated zero-violation DRC does not replace this gate.
3. Intentionally generate and manually review Gerber/drill plots before any fabrication order; none is published now.
4. Measure A/B input current, output levels and temperature at 12.0 V and 16.8 V.
5. Capture A-open, B-open, ALERT-low, 3.3 V-loss and MCU-stuck-high waveforms.
6. Prove both PWM outputs fall within 20 ms, then combine the board, relay and contactor in commissioning test E02.
7. Complete 20 kHz integrity, temperature, vibration, connector-retention and EMC testing.

Physical status: `NOT_RUN`; safety certification: `NONE`; manufacturing release: `NOT_RELEASED_PEER_REVIEW_GERBER_AND_PHYSICAL_VALIDATION_REQUIRED`.

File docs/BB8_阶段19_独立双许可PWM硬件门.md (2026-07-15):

# BB-8 阶段19：独立双许可 PWM 硬件门原理图与布线PCB/DRC门

> 结论：**64组布尔组合、输入电流、逻辑电平、功耗降额和50 × 35 × 15 mm机械包络的解析检查全部通过；确定性生成的KiCad 10正式原理图为0项ERC违规，两层50 × 35 mm PCB已完成布线，并取得0项DRC违规、0个未连接项。34个器件引用、91条规范引脚连接和21个网络完成原理图/PCB双重交叉审计。但独立原理图与布局同行复核、Gerber/钻孔发布复核、实装板和示波器证据仍缺失，整体状态必须保持 `HOLD_PCB_CAD_BENCH_AND_SAFETY_VALIDATION_REQUIRED`。**

## 为什么必须新增这一阶段

阶段17确认MDD20A只有PWM+DIR，没有独立EN，而且PWM低的官方行为是制动，不是电气隔离。阶段18只在电源舱里保留了50 × 35 × 15 mm门板空间。阶段19把这个空白收敛为可机器审计的正式原理图和两层布线PCB/DRC参考设计，同时保留安全继电器和常开SW60接触器作为真正的母线去能路径。

## 三条独立许可链

左右两路都执行同一个公式：

`PWM_OUT = LOGIC_POWER_OK ∧ PWM_IN ∧ SAFE_A_OK ∧ SAFE_B_OK ∧ ALERT_N`

| 级 | 器件 | 功能 | 失效目标 |
| --- | --- | --- | --- |
| 输入A/B | 2 × Vishay VO617A-4 | 把12.0–16.8 V“上电才允许运行”回路隔离成3.3 V许可 | 任一路断线或撤电，许可拉低 |
| 许可A | TI SN74LVC2G08 U3 | 左右PWM分别与`SAFE_A_OK`相与 | A路单独可阻断两路PWM |
| 许可B | TI SN74LVC2G08 U4 | U3输出分别与`SAFE_B_OK`相与 | B路单独可阻断两路PWM |
| 电流告警 | TI SN74LVC2G08 U5 | U4输出分别与双INA226开漏`ALERT_N`相与 | 任一硬件ALERT可直接阻断两路PWM |
| 母线去能 | 安全继电器 + 常开接触器 | 与门板并行撤销电机母线 | PWM低不能替代这一层 |

`DIR_L/R`只是直通信号，不属于安全链；因此本设计只允许MDD20A的sign-magnitude模式。

## 厂商数据与解析点

- [TI SN74LVC2G08数据表](https://www.ti.com/lit/ds/symlink/sn74lvc2g08.pdf)：3.0–3.6 V时`VIH ≥ 2.0 V`、`VIL ≤ 0.8 V`；-40–125 °C、3.3 V ±0.3 V时单级传播延迟最大5.3 ns；`Ioff`支持掉电防回灌。
- [Vishay VO617A数据表](https://www.vishay.com/docs/83430/vo617a.pdf)：VO617A-4在`IF=5 mA、VCE=5 V、25 °C`时CTR为160–320%；`IF=5 mA、IC=1 mA`时`VCE(sat)`最大0.4 V。25 µs饱和关断只是典型值，不能当作最坏值。
- [Cytron MDD20A产品页](https://sg.cytron.io/p-20amp-6v-30v-dc-motor-driver-2-channels)：输入兼容1.8/3.3/5/12 V逻辑，PWM最高20 kHz。
- [JST XH官方目录](https://www.jst-mfg.com/product/pdf/eng/eXH.pdf)：2.5 mm间距；标准顶部型安装高度9.8 mm，配AWG22时额定3 A。

在12.0 V、采用数据表1.65 V正向压降上界时，2.00 kΩ输入电阻提供5.175 mA，达到CTR的5 mA测试点；在16.8 V和1.0 V压降时为7.900 mA。最坏电阻功耗0.12482 W，0.5 W器件有4.006×降额。光耦发射极输出按0.4 V饱和上界仍为2.9 V，高于LVC的2.0 V高电平门槛；4.7 kΩ下拉负载约0.617 mA，低于数据表1 mA饱和测试电流。

三片LVC级联的数字逻辑传播上界为15.9 ns，但光耦只有典型关断值，因此**20 ms总去能合同仍只能通过示波器实测证明**。

## 机械与制造边界

- PCB为50 × 35 × 1.6 mm两层板，四个Ø3.2 mm非金属化孔严格位于距板原点(3,3)、(47,3)、(3,32)、(47,32) mm；JST XH最高9.8 mm，PCB加器件高11.4 mm。再计入3.0 mm绝缘安装柱后总安装高14.4 mm，阶段18的15 mm空间实际只余0.6 mm，必须用实物复核。
- OpenSCAD源文件只表达板框、孔和器件包络，不含焊盘、铜箔、阻焊、丝印、爬电距离或线束弯曲半径。本机OpenSCAD 2021.01无头导出未在限定时间内完成，因此本阶段不声称已有STL。
- Blender 中的23个板件/器件包络标为 `non_fabrication_reference`：它们可以进入带属性的GLB和内部三视图用于设计复核，但必须从150件制造清单及内部机构STL排除，不能伪装成可打印零件。
- 这23个参考包络已写入唯一主工程并完成关闭后重开审计。Blender 5.1.2确认386个总对象、182个内部对象、150个制造对象、9个工程标记和23个阶段19参考对象；主文件SHA-256为 `ecd9a8b02db7c0b253c06005aaf16e7a8bf10147f8adec9c8900415e18b38af4`。150行制造清单、内部机构STL、动画GLB和内部正/侧/俯三视图均已重导出。
- 正式`.kicad_sch`与`.kicad_pcb`均可确定性生成。KiCad 10.0.4报告0项ERC违规、0项PCB DRC违规和0个未连接项；跟踪板与临时重生成板的UUID无关结构哈希一致，34个器件引用、91条规范引脚连接、21个网络、1614段走线、54个过孔和两块3V3/GND铜区全部进入机器核验。当前仍没有独立原理图/布局同行复核、Gerber或钻孔发布包；任何PCB厂家下单都不被本阶段授权。

## 已发布证据

- [机器合同](../engineering/stage19_dual_permissive_gate_contract.json)
- [64行真值表](../engineering/stage19_gate_truth_table.csv)
- [预选BOM](../engineering/stage19_gate_bom.csv)
- [引脚网表](../engineering/stage19_gate_netlist.csv)
- [当前HOLD结果](../engineering/stage19_dual_permissive_gate_results.json)
- [Blender重开审计与导出哈希](../engineering/stage19_blender_reopen_audit.json)
- [验证器](../tools/verify_dual_permissive_gate.py)
- [KiCad正式原理图](../hardware/stage19_dual_permissive_gate/stage19_dual_permissive_gate.kicad_sch)
- [KiCad ERC报告](../engineering/stage19_kicad_erc.json)
- [KiCad连接导出](../engineering/stage19_kicad_netlist.xml)
- [KiCad原理图验证结果](../engineering/stage19_kicad_verification.json)
- [KiCad原理图PDF](../output/pdf/BB8_stage19_dual_permissive_gate_schematic.pdf)
- [KiCad验证器](../tools/verify_stage19_kicad.py)
- [KiCad布线PCB](../hardware/stage19_dual_permissive_gate/stage19_dual_permissive_gate.kicad_pcb)
- [PCB DRC 0违规报告](../engineering/stage19_kicad_pcb_drc.json)
- [PCB结构与重生成验证结果](../engineering/stage19_kicad_pcb_verification.json)
- [PCB生成器](../tools/generate_stage19_kicad_pcb.py)
- [PCB验证器](../tools/verify_stage19_kicad_pcb.py)
- [PCB预览导出器](../tools/export_stage19_kicad_pcb.py)
- [PCB等轴测复核图](../output/pcb/BB8_stage19_gate_pcb_isometric.png)
- [硬件包说明](../hardware/stage19_dual_permissive_gate/README.md)

## 下一道不可跳过的门

1. 对已捕获的KiCad原理图及安全假设做独立同行复核；
2. 独立人工复核已布线PCB的隔离区、安装孔、丝印极性、测试点和线束出口；自动DRC通过不能替代这一门；
3. 明确生成并人工检查Gerber/钻孔后才允许制造；当前仓库未发布这两类制造文件；
4. 分别在12.0 V与16.8 V测A/B输入电流、输出高低电平和温升；
5. 对A断开、B断开、ALERT拉低、3.3 V掉电、MCU PWM卡高逐项抓示波器波形；
6. 证明两路PWM均在20 ms内拉低，再与安全继电器和接触器组合完成E02；
7. 完成20 kHz、温度、振动、连接器保持力与EMC试验。

实物状态：`NOT_RUN`；安全认证：`NONE`；制造发布：`NOT_RELEASED_PEER_REVIEW_GERBER_AND_PHYSICAL_VALIDATION_REQUIRED`。

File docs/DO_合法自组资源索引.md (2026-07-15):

# D-O 合法自组资源索引

## 先说结论

截至 2026-07-15，仍未找到一个同时包含完整机械、控制源码、电气设计、明确再分发条款和真机验证证据的 D-O 整机开源包。已经找到免费与付费模型候选，但它们必须按“可动开发版、静态模型、关节展示模型”分开使用。当前可执行路线是：

1. 通过 Mr Baddeley Patreon 合法获得 V2 机械文件；
2. 使用 Printed Droid / Dozuki 的免费装配与接线文档；
3. 使用 PrintedDroid v3.4.3 控制源码，并遵守 README 内嵌的个人非商业许可；
4. 将 Mantis Hacks 当作升级设计和 BOM 参考，不宣称获得了 Matt Denton 的 CAD/代码。

## 资源矩阵

| 资源 | 内容 | 可得性 | 许可/边界 |
|---|---|---|---|
| Mr Baddeley D-O V2 | STL / Fusion 机械设计 | Patreon 会员 | 付费不等于开源；按创作者条款个人使用 |
| Printed Droid D-O | BOM、控制板、说明文档 | 公开网页 | 文档页未见统一开放硬件许可 |
| D-O-Printed-Droid GitHub | Arduino C++、v1–v3.4.3 | 源码公开 | 根目录无 LICENSE；v1.1/v2.1/v3.4 README 有自定义个人非商业许可，不属于 OSI 开源 |
| Printed Droid 官网 12 个附件 | Mega/AIO32 固件、英德手册、旧接线页、60 mm 支架 | 公开下载，本机已哈希固定 | 只作本机个人参考；未见覆盖全部附件的统一再分发许可 |
| AIO32 v2.1 ZIP | ESP32-S3 实验固件，22 个源码文件；已在隔离工具链编译通过 | 公开下载 | 无包级 LICENSE；只有部分文件有 Apache 标记；无 KiCad/Gerber，整体不能称为 OSI 开源或开放硬件 |
| Dozuki D-O Assembly | 五章装配指南 | 免费阅读 | 机械打印件仍指向 Patreon |
| Mantis Hacks #1–#5 + 轮胎视频 | 设计演进、电子、轮胎、BOM | 6个公开视频条目 | 六条公开描述未给出 Matt 改版 CAD/程序下载及许可 |
| DO Stand 60mm | 无轮通电测试支架 STL | 公开下载 | 非整机结构件；未附明确再分发许可 |
| Denton V1 / Thingiverse | 分组件 STL、3D PDF、可动机构思路 | 免费；页面标 CC BY 4.0 | WIP；页面仍写头部缺失、STEP 待后续；基于 Baddeley 私下提供的 CAD，衍生几何再许可权需复核；文件包尚未下载审计 |
| WF3D / Printables | 约 300 mm、32 个文件的分色模型 | 免费；CC BY-NC-SA 4.0 | 静态展示模型，不含驱动、平衡或控制设计 |
| CalebTimoteo / Printables | 11 个文件的家居摆件 remix | 免费；CC BY-NC 4.0 | WIP 静态模型，不含驱动系统 |
| JRIZZ / Cults | Fusion 360 F3Z、STL、机器人端与遥控端 Arduino 草图 | 付费；CULTS Private Use | 页面称可动但仍在开发；未购买、未验包、未做真机验证；数字文件不得公开再分发 |
| Gambody Assembly + Action | 116 个 STL、1:1/缩比版本、关节与发动机/电池空间 | 付费；Personal use | 是可关节展示/改装基础，不包含控制源码、平衡控制或完整电气包 |
| MakerWorld 23859 | 搜索发现的 D-O 条目 | 页面受 Cloudflare 阻断 | 文件、作者、许可与用途均未核验，不列为可用开源资源 |

## 直接链接

- D-O 总页：https://www.printed-droid.com/kb/d-o/
- 28 页装配 PDF：https://www.printed-droid.com/wp-content/uploads/2022/07/DO-Instructions-Pt1.1.pdf
- V2 接线 PDF：https://www.printed-droid.com/wp-content/uploads/2022/07/DOV2-Wiring-diagram-notes.pdf
- Dozuki 装配：https://d-o.dozuki.com/c/D-O_Assembly
- 控制源码：https://github.com/PrintedDroid/D-O-Printed-Droid
- 控制与供电板：https://www.printed-droid.com/kb/d-o-control-and-power-board/
- AIO32 v2.1 固件附件：https://www.printed-droid.com/wp-content/uploads/2020/09/D-O_AIO32_v2.1.zip
- AIO32 v2.1.1 英文手册：https://www.printed-droid.com/wp-content/uploads/2020/09/D-O_AIO32_v2_User_Handbook_v2.1.1.pdf
- 官网 v3.4 历史附件：https://www.printed-droid.com/wp-content/uploads/2020/09/D-O_ibus_v3.4.zip
- Arduino Mega 2560 Serial0 引脚：https://docs.arduino.cc/language-reference/en/functions/communication/serial/
- 60 mm 无轮调试支架：https://www.printed-droid.com/wp-content/uploads/2020/09/DO-Stand-60mm.stl
- Patreon：https://www.patreon.com/mrbaddeley
- D-O V2 公开帖：https://www.patreon.com/posts/d-o-v2-33070756
- Mantis Hacks 播放列表：https://youtube.com/playlist?list=PLTSAQ5KEjPVCldgA1t-KT1lRTKJdAY7er
- Denton V1 Thingiverse：https://www.thingiverse.com/thing:4189546
- WF3D 30 cm 静态模型：https://www.printables.com/model/147063-star-wars-d-o-droid
- Printables 家居摆件 WIP：https://www.printables.com/model/1269542-d-o-droid-star-wars-home-decor
- JRIZZ Cults 可动开发版：https://cults3d.com/en/3d-model/gadget/d-o-droid-star-wars-droid
- Gambody Assembly + Action：https://www.gambody.com/premium/d-o-droid
- MakerWorld 待核验条目：https://makerworld.com/en/models/23859-star-wars-d-o-droid

## 本地已固定版本

- 仓库：`third_party/D-O-Printed-Droid`
- 提交：`e90aacdbe26a62fd4f0229d5504a3f2f3c409055`（2026-06-08）
- 推荐固件：`D-O_ibus_v3.4/D_O_printed_droid_rc_ibus_v3.4.3.ino`
- 2026-07-15 复核上游 `main` 仍为固定提交 `e90aacdbe26a62fd4f0229d5504a3f2f3c409055`
- 官网控制板页 12 个附件已下载到 Git 忽略目录 `third_party/do_public_resources/`，每个 URL、字节数和 SHA-256 写入机器清单
- 公开 `D-O_ibus_v3.4.zip` 实际是 v3.4.0；当前制作仍使用 GitHub 固定的 v3.4.3
- AIO32 ZIP 已核验为 23 个成员（22 个源码 + README）、0 个 KiCad/Gerber、0 个机械模型、无包级 LICENSE
- AIO32 已用 ESP32 core 3.3.7 实编译通过：Flash 41%、RAM 15%；手册遗漏的 `SensorLib` 0.4.1 是编译器发现的必要依赖，证据在 `engineering/do_aio32_firmware_compile.json`
- 完整自动审计：`python3 tools/audit_do_resources.py`
- Mantis 六条视频描述审计：`engineering/do_mantis_video_audit.json`
- 可复现获取：`tools/fetch_do_public_resources.sh`
- 审计说明：`docs/DO_资源审计与自组入口.md`
- 采购门控 BOM：`engineering/do_self_build_bom.csv`
- 分阶段调试路线：`docs/DO_自组采购与调试路线.md`

## 公开模型候选的正确用法

1. **Denton V1 是免费可动候选，不是已完成整机包。** Thingiverse 页面级元数据标注 CC BY 4.0，并写明有分组件 STL 与 3D PDF；同一页面也明确标注 WIP、头部尚未完成、STEP 以后再加。页面还说明模型基于 Michael Baddeley 私下发给作者的 CAD，因此在实际采用或再发布衍生文件前，要同时核对压缩包内容和衍生授权来源。
2. **JRIZZ / Cults 是目前最接近“机械 + Arduino”的整合候选，但它是付费私用开发版。** 页面列出 Fusion 360 主装配、机器人端/遥控端两个 Arduino 草图、打印件和硬件架构；页面也说设计仍在开发。购买属于外部付费且接受私用条款的动作，必须等用户明确确认；购买前本项目不会获取、镜像或宣称已验证。
3. **两个 Printables 条目是静态模型。** WF3D 版本约 300 mm、32 个文件，许可为 CC BY-NC-SA 4.0；家居摆件版本为 11 文件 WIP remix，许可为 CC BY-NC 4.0。它们可以帮助外形、分色和打印，但不能替代可平衡、可驱动的机械结构。
4. **Gambody 是付费关节展示/改装底座。** 页面列出 116 个 STL、518 mm 高的“life-size”版本、可动头部和可替换的发动机/电池假件，但没有控制源码、电气设计或平衡算法，不能按完整机器人包验收。
5. **MakerWorld 只保留为待核验线索。** 2026-07-15 审计时页面被 Cloudflare 阻断，未取得足够证据确认许可证、作者、文件或用途。

上述六条候选已经写入 `engineering/do_resource_manifest.json` 的 `external_model_candidates`。清单只记录原始链接和页面证据，不镜像任何第三方数字模型。

## Mantis Hacks 视频中的主要 BOM

- Arduino MKR WiFi 1010、MKR Proto Shield、MKR IMU Shield、MKR Motor Carrier
- Lynxmotion LSS ST1、Power Hub、32T 齿轮、串口线/适配板
- Dynamixel XL-320，后续改用 AX-18A / AX-12A
- Pololu 25D 带编码器减速电机
- 6 V 5000 mAh NiMH
- 25×32×4、8×12×3.5、4×11×4 轴承，8 mm IGUS 轴
- Adafruit 16 MB Sound FX 2×2 W、2 W 喇叭、Spektrum 遥控

播放列表实际由 **5 集编号构建视频 + 1 个 TPU 轮胎打印视频**组成。2026-07-13 对六条公开视频描述逐条读取后，没有发现 GitHub、GitLab、Google Drive、Dropbox 或其他 Matt 改版 CAD/控制程序发布链接；描述主要指向两个 Facebook 群、Mr Baddeley Patreon、Matt 的 Threeding 主页以及零件/联盟购买页。#4 的描述反而明确说明原始 CAD 由 Michael Baddeley 直接发送给 Matt，Matt 在其上修改舵机、驱动和电子方案。这支持“视频是设计与 BOM 证据，不是公开源码包”的边界，但不排除私有群、付费区或未索引来源以后出现文件。

## 目前仍缺失

- 合法免费、完整且已验包的可动 D-O STL/Fusion 机械包
- Matt Denton 改版 CAD 和控制程序
- Printed Droid GitHub 当前没有机械模型；Denton V1 免费候选仍是 WIP，JRIZZ 与 Baddeley 路线仍需分别接受 Cults/Patreon 的付费条款
- Printed Droid 控制板 KiCad/Gerber 源文件
- AIO32 手册所称共享 GitHub 硬件 KiCad 的实际公开位置；固定仓库唯一 `main` 分支和公开 ZIP 都没有这些文件
- 电影 D-O 的官方尺寸、公差和声音授权

## 新增源码与版本阻断门

固定的 v3.4.3 草图一边把舵机连接到 Mega D0/D1，一边启用 `Serial.begin(9600)`。官方 Mega 映射表显示 D0/D1 就是 RX0/TX0。项目现在提供固定哈希转换器，将四路舵机移到 D22–D25，并已在 Mega 2560 编译通过；`DO-SRC-001` 因此前进为 `UPSTREAM_CONFLICT_VARIANT_COMPILED_HOLD_PHYSICAL_CONTINUITY`。这不是实物通过：D22–D25 导通、USB/Serial0 和四路舵机脉宽仍必须上台架。

Printed Droid 控制板页面内嵌的是 v2.1 接线表（D2/D3/D4/D5），而当前 v3.4.3 源码和 GitHub README 是 D0/D1/D5/D6。项目已发布只含本项目生成信息的 [安全变体线束合同](../engineering/do_safe_pin_variant_wiring.csv) 和 [编译证据](../engineering/do_safe_pin_variant_compile.json)，状态为 `DO-SRC-002 / VARIANT_WIRING_GENERATED_HOLD_PHYSICAL_CONTINUITY`。不得把旧网页表、未改原版和 D22–D25 变体混接；上电前仍要逐网导通。

同一页面的 `D-O_ibus_v3.4.zip` 内部仍是 v3.4.0。项目新增 `DO-SRC-003 / USE_PINNED_GITHUB_V3_4_3`：附件保留为历史证据，不作为当前烧录输入。AIO32 已证明可编译，但仍保持实验分支和包级许可/HW-CAD 双 HOLD，不与 Mega v3.4.3 基线混为一条路线。

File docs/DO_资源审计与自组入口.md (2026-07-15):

# D-O 资源审计与自组入口

## 已落地的本地资源

- Printed Droid 控制仓库：`third_party/D-O-Printed-Droid`
- 固定提交：`e90aacdbe26a62fd4f0229d5504a3f2f3c409055`
- 当前推荐固件：`D-O_ibus_v3.4/D_O_printed_droid_rc_ibus_v3.4.3.ino`
- 目标控制器：Arduino Mega 2560
- 装配 PDF：`third_party/DO-Instructions-Pt1.1.pdf`
- 接线 PDF：`third_party/DOV2-Wiring-diagram-notes.pdf`
- 无轮调试支架：`third_party/DO-Stand-60mm.stl`（非整机结构件，许可未明确，不对外再打包）
- 官方控制板页面的 12 个公开附件：`third_party/do_public_resources/`（本机核验副本，Git 忽略）
- AIO32 v2.1 公开附件：23 个成员，其中 22 个源码文件和 1 个 README；未发现 KiCad/Gerber 或包级 LICENSE
- 机器可读清单：`engineering/do_resource_manifest.json`
- 外部模型候选：机器清单内 `external_model_candidates` 共 6 条，覆盖免费可动 WIP、付费可动开发版、免费静态模型、付费关节展示模型和 1 条待核验线索
- Mantis 六条视频描述审计：`engineering/do_mantis_video_audit.json`
- 固件编译证据：`engineering/do_firmware_compile.json`
- AIO32 编译证据：`engineering/do_aio32_firmware_compile.json`
- 26 项采购门控 BOM：`engineering/do_self_build_bom.csv`
- D01–D16 自组路线：`docs/DO_自组采购与调试路线.md`

运行 `python3 tools/audit_do_resources.py` 可重新核验提交、固件、许可证位置、机械文件缺口、12 个官网附件及其 SHA-256。运行 `python3 tools/audit_do_mantis_videos.py` 只读取六条公开视频元数据与描述链接，不下载视频。运行 `tools/fetch_do_public_resources.sh` 可重新获取公开资料；脚本不会购买、抓取或绕过 Patreon 付费资源，也不会自动切换仓库提交。官网附件只保存在 Git 忽略目录：公开可下载不等于允许本仓库再分发。

## 固件编译门

`tools/compile_do_firmware.sh` 已在项目隔离的 Arduino 环境中，以 `arduino:avr:mega` 编译 v3.4.3 成功。工具链为 Arduino CLI 1.5.1、AVR core 1.8.8、IBusBM 1.1.4、DFRobotDFPlayerMini 1.0.6、Servo 1.3.0。结果为 Flash 43,198 / 253,952 B（17%），全局 RAM 1,516 / 8,192 B（18%）。这证明源码可编译，不等于真机平衡、接线或安全验收通过。

`tools/compile_do_aio32_firmware.sh` 也已从官网原始 ZIP 的固定 SHA-256 重建临时草图，并以 `esp32:esp32@3.3.7`、Adafruit Feather ESP32-S3 TFT 目标编译成功：Flash 549,831 / 1,310,720 B（41%），全局 RAM 49,652 / 327,680 B（15%）。首次编译暴露手册依赖表遗漏 `SensorLib`（缺少 `SensorQMI8658.hpp`）；补装官方 Library Manager 的 SensorLib 0.4.1 后通过。此结果只解除“源码能否编译”的疑问，不解除包级 LICENSE、KiCad/Gerber、实物接线、运动与安全 HOLD。

## 许可证结论

仓库根目录没有统一 `LICENSE` 文件，但 v1.1、v2.1、v3.4 三个版本 README 内都包含相同的自定义 `NON-COMMERCIAL LICENSE`：允许个人非商业使用、复制、修改和分发，同时要求保留声明、署名，并禁止商业用途。

所以准确说法是“公开源码，受自定义个人非商业许可约束”，不是“完全无许可”，也不是 OSI 定义的开源软件。旧版 Mega 与 Nano 目录没有同样清楚的内嵌条款，优先使用 v3.4.3，并随衍生副本保留 v3.4 README。

## 能直接开始的部分

1. 按 Printed Droid 装配 PDF 和 Dozuki 五章指南理解机械装配顺序。
2. 按接线 PDF 准备 Arduino Mega 2560、Cytron MDD10A、MPU6050、遥控接收机、舵机和 DFPlayer Mini。
3. 安装 `IBusBM` 与 `DFRobotDFPlayerMini`；`Servo`、`EEPROM`、`SoftwareSerial`、`Wire` 和 `avr/wdt` 由 AVR 工具链提供。
4. 先在无负载台架上检查急停、方向、限幅和失控保护，再连接执行器。

公开说明存在必须先解决的硬件冲突：仓库根 README 写一块 Cytron MDD10A 双路驱动，v3.4 README 写两块 MD10C。驱动电机、减速比、四个舵机负载和真实峰值电流也未冻结。因此采购表把这些项标为 HOLD，而不是把来源中的示例值冒充最终选型。

源码还存在第二个硬件冲突门。v3.4.3 把 `MAINBAR_SERVO_PIN` 和 `HEAD1_SERVO_PIN` 分别固定为 D0、D1，并实际调用四路 `Servo.attach()`；同一草图又执行 `Serial.begin(9600)`，把 USB 配置菜单放在 Serial0。Arduino Mega 2560 官方映射中 D0 是 RX0、D1 是 TX0，因此上游原版确实发生物理引脚争用。项目现已加入 `tools/build_do_safe_pin_variant.py`：工具只接受固定提交和 SHA-256，把四路舵机改到 D22–D25，保留 Serial0，并以 Mega 2560 成功编译。状态为 `UPSTREAM_CONFLICT_VARIANT_COMPILED_HOLD_PHYSICAL_CONTINUITY`；软件冲突已在变体中消除，但实体导通、USB/串口和四路脉宽仍需台架证明，舵机电源不放行。

官网还存在两个版本化入口冲突。控制板页面内嵌的 **v2.1** 接线表把四个舵机写成 D2/D3/D4/D5，而固定的 **v3.4.3** 源码与当前 GitHub README 使用 D0/D1/D5/D6；页面名为 `D-O_ibus_v3.4.zip` 的附件内部版本头仍是 **3.4.0**，不是固定仓库中的 3.4.3。项目已生成绑定原始提交、原始/修改后 SHA-256 的 [D22–D25 线束合同](../engineering/do_safe_pin_variant_wiring.csv) 与 [编译证据](../engineering/do_safe_pin_variant_compile.json)，故 `DO-SRC-002` 前进为 `VARIANT_WIRING_GENERATED_HOLD_PHYSICAL_CONTINUITY`；网页 ZIP 仍只作历史参考。

AIO32 v2.1 是另一条实验性 ESP32-S3 控制路线，不是当前 Mega 基线的无条件替代。其公开 ZIP 有 22 个源码文件，部分文件出现 Apache 2.0 标记，但压缩包没有统一 LICENSE；随附手册声称源码和硬件 KiCad 在共享 GitHub 仓库，而 2026-07-13 固定的唯一 `main` 分支及该 ZIP 中都没有 AIO32 KiCad/Gerber。故整体许可与硬件可制造性保持 `HOLD_PACKAGE_LICENSE_AND_HARDWARE_CAD_NOT_FOUND`，不能因为个别文件头或手册一句话就把整包称为开放硬件。

## 尚不能凭公开资源完成的部分

- 该 GitHub 仓库中机械 CAD/STL/STEP/Fusion 文件数量为 **0**。
- Printed Droid 控制板页面另有一个公开下载的 60 mm 无轮调试支架 STL，但没有明确再分发许可，也不能替代整机机械模型。
- Mr Baddeley D-O V2 STL/Fusion 属 Patreon 付费资源；购买和接受其使用条款需要用户明确确认。
- Thingiverse 的 **Denton V1** 是免费可动机械候选，页面级许可证为 CC BY 4.0，并称含分组件 STL 与 3D PDF；但同一页面仍明确标注 WIP、头部缺失、STEP 尚未发布。其描述还写明基础 CAD 由 Michael Baddeley 私下发送，因此文件包完整性和衍生再许可权都必须在采用前复核。本项目未下载或镜像该文件包。
- Cults 的 **JRIZZ D-O** 页面列出 Fusion 360 F3Z、机器人端/遥控端 Arduino 草图、STL 和完整硬件思路，是目前最接近机械与控制整合的候选；但它是付费 `CULTS - Private Use` 开发版，页面也明确说仍在开发。购买、接受条款和获取文件必须等待用户明确确认。
- Printables 的 **WF3D 30 cm / 32 文件**版本（CC BY-NC-SA 4.0）与 **CalebTimoteo 11 文件 WIP remix**（CC BY-NC 4.0）都是静态模型；不能替代驱动、平衡和安全结构。
- Gambody 的付费 Personal-use 模型有 116 个 STL、518 mm 高的 life-size 版本、可动头部和发动机/电池改装空间，但没有控制源码、电气设计或平衡算法，不能算作可运行整机包。
- MakerWorld 23859 页面在 2026-07-15 审计时被 Cloudflare 阻断，作者、文件、许可和用途均保持 `UNVERIFIED`。
- Mantis 播放列表实际为5集编号构建视频加1个轮胎打印视频；六条公开描述没有 Matt 改版 CAD/控制程序的直接下载链接或许可证。#4 说明基础 CAD 由 Michael Baddeley 直接发给 Matt，而不是在视频描述中公开发布。
- Printed Droid 控制与供电板仓库及核验过的 AIO32 公开附件中都没有可验证的 KiCad/Gerber 源文件；这与 AIO32 手册的仓库声明不一致，需等待上游发布位置澄清。

官方 Mega 2560 串口引脚参考：https://docs.arduino.cc/language-reference/en/functions/communication/serial/

因此，本阶段已经把合法可用的控制与装配资料拉到本地，并把六条外部模型候选按用途和许可分层。结论不再是“网上没有免费 D-O 模型”，而是：**尚未找到一个完整、可公开再分发、同时含机械、控制、电气和真机验证证据的 D-O 整机开源包**。Denton 免费候选仍不完整；JRIZZ/Baddeley/Gambody 都有付费或私用边界；静态模型不能冒充可运行机器人。

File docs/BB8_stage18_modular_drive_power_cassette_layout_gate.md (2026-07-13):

# BB-8 Stage 18: Modular Drive-Power Cassette Layout Gate

> Current result: **HOLD_PHYSICAL_FIT_AND_INTERFACE_VALIDATION_REQUIRED**. The catalogue-envelope layout is now written into the sole Blender master and passes the audit after reopening. No component has been purchased or physically fitted, powered, thermally tested or commissioned.

## Purpose

Stage 17 screened the catalogue ratings of MDD20A, a provisional 30 A MIDI fuse, SW60 and a P28A 4S2P pack candidate. The Stage-15 Blender master still contained two generic 52 x 34 mm driver envelopes. Stage 18 separates official dimensions from unresolved assumptions, lays out and writes:

- an enclosed REC Active BMS 4S candidate;
- one Cytron MDD20A dual driver;
- an Albright SW60 normally-open contactor;
- a service envelope for the replaceable MIDI fuse;
- the REC BMS external current shunt;
- an independently verified dual-channel MDD20A gate-board keepout;
- the safety relay and dual-channel E-stop receiver.

## 4S BMS candidate

The official REC Active BMS manual states:

- dedicated four-cell operation;
- 111 x 135 x 44 mm enclosed, or 109 x 100 x 38 mm including connector without the enclosure;
- up to two DS18B20 pack-temperature sensors;
- up to 2 A active balancing;
- external low-side shunt measurement with a documented +/-200 A range;
- contactor-control relays, charge-disable output, CAN and RS-485.

It is not an inline 30 A MOSFET protection board. It depends on an external shunt and contactors, which is directionally compatible with the current dual-channel E-stop and SW60 architecture. Chemistry, exact order code, shunt and coil interface still require supplier confirmation.

## Analytical layout

| ID | Module | Orientation | Envelope | Status |
|---|---|---|---|---|
| BMS01 | REC Active BMS 4S | Vertical, chassis left | 44 x 111 x 135 mm | Official enclosed envelope; analytical fit only |
| DRV01 | MDD20A | Vertical, chassis right | board 1.6 x 88.9 x 78.74 mm; 25 mm height keepout | Height is an explicit conservative assumption |
| CON01 | SW60 | Upper rear | 81 x 37 x 28.1 mm | Order code, suppression and cable sweep remain open |
| FUS01 | MIDI fuse | Right of contactor | 60 x 25 x 25 mm service keepout | Catalogue fuse body is 41 x 16 mm; holder needs measurement |
| SHN01 | External BMS shunt | Rear left | 50 x 25 x 15 mm keepout | Part, resistance, pulse rating and Kelvin terminals are open |
| GAT01 | Dual-channel gate | Front right | 50 x 35 x 15 mm keepout | No released PCB exists |

## Machine result

`tools/verify_power_cassette_layout.py` checks shell clearance, candidate-to-candidate separation and avoidance of the battery, motors, drive wheels, ballast, magnetic mast and four stabiliser arms. It also refuses to turn unresolved freeze gates into a physical PASS.

- Eight candidates pass the analytical AABB screen.
- Minimum radial shell clearance: **27.643 mm**.
- Minimum candidate-pair separation: **7.500 mm**.
- Minimum separation from protected internal hardware: **6.000 mm**.
- Twelve physical/interface freeze gates remain unresolved.
- Overall result stays `HOLD_PHYSICAL_FIT_AND_INTERFACE_VALIDATION_REQUIRED`.

This conservative axis-aligned screen does not replace real harness bend, tool access, connector insertion, moving-sweep or sealed-shell thermal verification.

## Blender write and reopen audit

After the user explicitly approved discarding the previous unsaved GUI state, the workflow retained one Blender process and one master project. The overwritten on-disk master SHA-256 is `3b774f3e02c89e15922aac48629a43d4765d37078acad88ccf34f6316827d5c3`.

Completed and verified:

- `blender/stage18_power_cassette_geometry.py` creates the envelopes, mounts, two temperature sensors and fifteen power/safety paths;
- `blender/stage18_apply_power_cassette.py` replaces Stage-15 generic envelopes, rerenders the internal views and saves the sole master;
- `blender/audit_bb8.py` confirms 363 total objects, 159 internal objects, 150 fabrication objects, nine engineering annotations, 39 Stage-18 objects, eight candidate IDs, the official MDD20A hole pattern, dual temperature channels and the NOT_RUN boundary after reopening;
- the 150-row fabrication manifest, internal STL, animated GLB and front/side/top internal views were re-exported; Blender was finally restored to the saved master with no unsaved marker.

The audit proves that the saved file reopens with consistent object structure and analytical contracts. It does not promote catalogue envelopes to a physical-fit or powered-test PASS.

## Remaining gates

1. Measure purchased-sample MDD20A total height, terminal sweeps, BMS mounting interface and MIDI holder.
2. Freeze REC chemistry/order code/shunt/contactor-coil interfaces.
3. Release and bench-test the independent dual-channel gate PCB.
4. Complete all nineteen Stage-16 physical evidence gates.

## Official sources

- REC Active BMS 4S manual: <https://www.rec-bms.com/datasheet/Manual_ActiveBMS_4S_RV.pdf>
- Cytron MDD20A product page: <https://www.cytron.io/p-20amp-6v-30v-dc-motor-driver-2-channels>
- Albright SW60 data sheet: <https://www.albrightinternational.com/wpcms/wp-content/uploads/2020/08/SW60-Data-Sheet.pdf>
- Littelfuse MIDI data sheet: <https://www.littelfuse.com/~/media/automotive/datasheets/fuses/passenger-car-and-commercial-vehicle/bolt-down-fuses/littelfuse_midi_datasheet.pdf>

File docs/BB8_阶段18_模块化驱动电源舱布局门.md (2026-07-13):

# BB-8 阶段 18：模块化驱动电源舱布局门

> 当前结论：**HOLD_PHYSICAL_FIT_AND_INTERFACE_VALIDATION_REQUIRED**。目录尺寸的解析布局已写入唯一 Blender 主工程，并在重开后通过审计；没有购买、实物试装、上电、热试验或真机运行。

## 本阶段的目标

阶段17证明MDD20A、30 A MIDI、SW60和P28A 4S2P的目录额定处于合理量级，但阶段15 Blender仍是两块52 × 34 mm通用驱动器包络。阶段18先把官方尺寸与未冻结假设分开，计算并写入如何在Ø508 mm球壳内放入：

- REC Active BMS 4S带壳候选；
- 单块Cytron MDD20A双路驱动器；
- Albright SW60常开主接触器；
- 30 A MIDI保险丝可更换空间；
- REC BMS外部分流器；
- 双通道MDD20A硬件门板空间；
- 安全继电器与双通道急停接收器。

## 4S BMS候选

REC Active BMS官方手册明确给出：

- 专用4串电芯；
- 带壳111 × 135 × 44 mm，无壳含连接器109 × 100 × 38 mm；
- 最多2个DS18B20电池温度传感器；
- 最高2 A主动均衡；
- 外部低边分流器电流测量，手册解析量程为±200 A；
- 接触器控制继电器、充电禁止输出、CAN和RS-485。

这个BMS不是串在主回路中的30 A MOSFET保护板；它依赖外部分流器与接触器。这与当前“双通道急停释放SW60”的架构方向一致，但具体化学体系、订货码、分流器和继电器线圈接口必须由厂商确认。

## 解析布局

| ID | 模块 | 布局方向 | 尺寸基线 | 状态 |
|---|---|---|---|---|
| BMS01 | REC Active BMS 4S | 竖直放在底盘左侧 | 44 × 111 × 135 mm | 官方带壳包络，仅解析通过 |
| DRV01 | MDD20A | 竖直放在右侧 | 板1.6 × 88.9 × 78.74 mm；高25 mm空间 | 高度为显式保守假设 |
| CON01 | SW60 | 后上方 | 81 × 37 × 28.1 mm | 订货码/抑制/线束扫掠未冻结 |
| FUS01 | MIDI保险丝 | 接触器右侧 | 60 × 25 × 25 mm服务空间 | 保险丝本体41 × 16 mm，底座待实测 |
| SHN01 | BMS外部分流器 | 后左侧 | 50 × 25 × 15 mm空间 | 阻值、脉冲和Kelvin端子未冻结 |
| GAT01 | 双通道硬件门 | 前右侧 | 50 × 35 × 15 mm空间 | 没有已发布PCB |

## 机器验证结果

`tools/verify_power_cassette_layout.py`同时检查球壳余量、候选模块间距、已有电池/电机/驱动轮/配重/磁头桅杆/稳定臂避让，并拒绝把未完成冻结门写成PASS。当前结果：

- 8个候选模块全部通过解析AABB检查；
- 球壳最小径向余量：**27.643 mm**；
- 候选模块之间最小分离：**7.500 mm**；
- 与受保护内部机构的最小分离：**6.000 mm**；
- 12个实物/接口冻结门仍未完成；
- 结果保持 `HOLD_PHYSICAL_FIT_AND_INTERFACE_VALIDATION_REQUIRED`。

这只是轴对齐包络的保守筛查，不能代替真实线束弯曲、螺丝工具路径、插拔空间、球壳运动扫掠和封壳热试验。

## Blender写入与重开审计

用户明确确认丢弃旧的未保存GUI状态后，仍只保留一个Blender进程和一个主工程。阶段18覆盖保存后的磁盘主文件SHA-256为 `3b774f3e02c89e15922aac48629a43d4765d37078acad88ccf34f6316827d5c3`。

已完成并验证：

- `blender/stage18_power_cassette_geometry.py`：生成候选包络、安装件、温度传感器和15段动力/安全线路；
- `blender/stage18_apply_power_cassette.py`：替换阶段15通用包络、重渲染内部三视图并保存唯一主工程；
- `blender/audit_bb8.py`：重开后确认363个总对象、159个内部对象、150个制造对象、9个工程标记、39个阶段18对象、8个候选ID、官方MDD20A孔位、双温度和NOT_RUN边界；
- 重新导出150项内部装配清单、内部机构STL、动画GLB及内部正/侧/俯三视图；Blender最终回到无未保存星号的主文件状态。

审计证明的是文件可重开、对象结构和解析契约一致，不把目录包络提升为实物试装或上电通过。

## 仍需完成

1. 购买样品后测量MDD20A总高、接线端扫掠、BMS安装孔和MIDI底座。
2. 冻结REC BMS化学体系/订货码/分流器/接触器线圈接口。
3. 发布并台架验证双通道硬件门PCB。
4. 完成阶段16全19项真机证据门。

## 官方来源

- REC Active BMS 4S手册：<https://www.rec-bms.com/datasheet/Manual_ActiveBMS_4S_RV.pdf>
- Cytron MDD20A产品页：<https://www.cytron.io/p-20amp-6v-30v-dc-motor-driver-2-channels>
- Albright SW60数据表：<https://www.albrightinternational.com/wpcms/wp-content/uploads/2020/08/SW60-Data-Sheet.pdf>
- Littelfuse MIDI数据表：<https://www.littelfuse.com/~/media/automotive/datasheets/fuses/passenger-car-and-commercial-vehicle/bolt-down-fuses/littelfuse_midi_datasheet.pdf>

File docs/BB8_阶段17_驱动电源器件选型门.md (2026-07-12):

# BB-8 阶段 17：驱动电源器件选型门

> 结论：**HOLD_COMPONENT_FREEZE_MEASUREMENTS_REQUIRED**。官方资料支持的候选额定筛选 15/15 通过，但这不是采购放行，也不是实物验证。电机堵转电流、MDD20A 再生路径/独立去能适配、保险丝 I²t、接触器具体订货码与释放时间、4S BMS、专业电池包设计和19项真机门仍未完成。

## 本阶段解决了什么

阶段15只有通用驱动器、保险丝、接触器和电池包络。阶段17将目录事实、计算值和未知项拆开，形成：

- `engineering/power_component_candidates.json`：厂商官方资料、候选型号、系统需求和冻结门；
- `tools/verify_power_component_selection.py`：重算电压/电流裕量并拒绝把未知项写成已冻结；
- `engineering/power_component_selection_results.json`：当前可机器审计的 HOLD 结果；
- `tests/test_power_component_selection.py`：覆盖正常 HOLD、驱动器欠额定拒绝和接触器抑制时序边界。

本阶段没有购买、焊接、制作电池包、上电、堵转或地面运行，也没有修改 Blender 主工程或新增 `.blend` 副本。

## 候选与当前判定

| 模块 | 候选 | 官方额定筛选 | 当前状态 |
|---|---|---|---|
| 电机 | Sha Yang Ye / Cytron IG42E-24K | 12 V、5.5 A额定、0.98 N·m、248 rpm | `HOLD_MEASURE_STALL_CURRENT`；官方商品页未给堵转电流 |
| 双路驱动 | Cytron MDD20A | 6–30 V；每路20 A连续/60 A峰值；3.3 V PWM/DIR兼容 | `HOLD_INTERFACE_AND_REGEN` |
| 主保险丝 | Littelfuse 498 MIDI 30 A暂定 | 32 VDC；30 A本体典型2.06 mΩ | `HOLD_STALL_I2T_CABLE_AND_TEMPERATURE` |
| 主接触器 | Albright SW60 SPST-NO，要求辅助触点 | 80 A热额定；48 V下120 A电阻性分断 | `HOLD_ORDER_CODE_SUPPRESSION_AND_DROP_TEST` |
| 电芯/电池包 | Molicel P28A，4S2P专业成包候选 | 14.4 V标称/16.8 V充电；理论70 A放电 | `HOLD_BMS_PACK_SHOP_AND_THERMAL_TEST` |
| BMS | 未冻结 | 要求4S、≥30 A放电、≥10 A再生充电、双温度和明确回灌路径 | `HOLD_NO_COMPACT_OFFICIAL_4S_CANDIDATE_FROZEN` |

## 解析裕量

输入沿用阶段15的21 A总峰值和每台电机5.5 A额定电流：

- MDD20A 每路20 A连续，相对电机额定为 **3.64×**；每路60 A峰值，相对解析10.5 A/路为 **5.71×**；30 V上限相对16.8 V母线为 **1.79×**。
- 暂定30 A MIDI保险丝相对21 A解析峰值为 **1.43×**，32 V额定相对16.8 V为 **1.90×**。这只能证明目录量级合理，不能代替堵转波形、导线温升和I²t配合。
- SW60 80 A热额定相对21 A为 **3.81×**，48 V下120 A电阻性分断相对21 A为 **5.71×**。
- 4S2P P28A理论最大放电70 A，相对21 A为 **3.33×**；按单体20 mΩ、4S2P拓扑估算电池内阻40 mΩ，与原50 mΩ解析假设同量级。

这些比值只基于目录和解析峰值。MDD20A的60 A峰值受板温限流，官方资料没有给峰值持续时间；不得按60 A持续能力使用。

## 两个关键接口阻塞项

### 1. MDD20A没有独立 EN

官方接口是双路PWM+DIR；PWM低的真值表行为是`Brake`，不是电气隔离。因此：

- 主接触器必须承担电池到驱动母线的硬去能；
- 原有“左右驱动EN”结构合同需实现为经过验证的双通道外部硬件门，并与接触器线圈同时受安全链控制；
- 不能把PWM归零、MCU停发命令或软件故障锁存描述成硬件断电。

### 2. 再生回灌未冻结

所选官方MDD20A页面/数据表没有明确本应用的再生能量处理能力。阶段16的P01再生母线门仍必须测量减速和急停时的母线峰值，并确认驱动器、BMS和电芯充电电流均未越界。

## 接触器释放时间陷阱

SW60官方资料给出的典型释放时间为：

- 无抑制：6 ms；
- 仅并联二极管：35 ms；
- 二极管+电阻：8–20 ms（取决于电阻）。

系统合同要求硬件去能不超过20 ms，所以普通续流二极管方案按目录典型值不合格。最终应使用经过器件钳位额定与EMC检查的抑制方案，并在实际线圈、温度和母线下实测释放时间；这里不直接给出可照抄的阻值。

## 几何边界

MDD20A官方二维图给出板外形约 **88.90 × 78.74 mm**，安装孔距 **83.82 × 73.66 mm**、4×Ø3 mm。它明显大于现有 Blender 中两块52 × 34 × 16 mm通用包络，而且官方二维图没有冻结板高。由于BMS、线束和具体布局尚未冻结，本阶段不冒险把候选目录图硬写入唯一主 `.blend`；正式布局更新必须以官方CAD/实物测量和维护空间联合验证为输入。

## 电池包安全边界

P28A数据表支持4.2 V充电、35 A最大放电和8.4 A最大充电/单体，但这不等于允许个人按本报告焊包。4S2P候选必须由合格电池包制作方冻结：电芯配组、镍带/汇流排、绝缘、熔断、温度传感、泄压、外壳、连接器、BMS、充电器与运输合规。

曾检查EMUS BMS mini作为官方资料参考；其手册写明5–16串，因此明确不适用于当前4S架构。没有合适BMS前不得采购散装电芯启动电池包制作。

## 采购前必须关闭的门

1. 在限流、轮子架空的夹具上测两台实际IG42E的启动和可控堵转电流波形。
2. 设计并台架验证MDD20A外部双通道硬件门；急停必须同时撤销接触器和控制输入。
3. 记录减速/急停再生母线波形，冻结驱动器与BMS回灌合同。
4. 用实测波形、线径、环境温度和连接器额定做30 A MIDI的I²t与热配合；必要时改额定。
5. 冻结SW60的12 V连续线圈、辅助触点、非锁存配置、安装方向和抑制方式，并实测≤20 ms释放。
6. 冻结带公开数据表的4S BMS和专业电池包设计。
7. 完成阶段16全部19项真机证据门，才允许解除整机运行HOLD。

## 官方资料

- Cytron MDD20A产品页与官方数据表：<https://www.cytron.io/p-20amp-6v-30v-dc-motor-driver-2-channels>
- Cytron IG42E-24K产品页：<https://www.cytron.io/p-12v-248rpm-10kgfcm-planetary-dc-geared-motor-with-encoder>
- Littelfuse MIDI 32 V数据表：<https://www.littelfuse.com/~/media/automotive/datasheets/fuses/passenger-car-and-commercial-vehicle/bolt-down-fuses/littelfuse_midi_datasheet.pdf>
- Albright SW60数据表：<https://www.albrightinternational.com/wpcms/wp-content/uploads/2020/08/SW60-Data-Sheet.pdf>
- Molicel INR-18650-P28A数据表：<https://www.molicel.com/wp-content/uploads/INR18650P28A-V2-80093.pdf>
- EMUS BMS mini手册：<https://emusbms.com/wp-content/uploads/2019/05/EMUS-BMS-mini-User-Manual-v0.9.pdf>

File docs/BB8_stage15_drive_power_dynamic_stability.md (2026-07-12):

# BB-8 Stage 15: Drive Power and Dynamic Stability

> Result: **PASS_ANALYTICAL_ONLY**. The stage-15 design point passes the current assumptions, but motor, driver, fuse, contactor, E-stop, wheel/shell traction and sealed-shell thermal tests all remain `NOT_RUN`.

## New physical contracts

- Blender now contains two 52 × 34 × 16 mm generic motor-driver installation envelopes, two heatsinks and eight M3 standoffs. No driver product is frozen.
- The explicit main-power path is battery positive → externally reachable service disconnect → main fuse → normally-open main contactor → left/right drivers → motors.
- The E-stop path has two normally-closed channels, a monitored safety relay, contactor feedback, manual reset and both driver-enable branches. First tests require a wired tether; wireless alone is not accepted.
- Fuse current, DC contactor breaking capacity, continuous/peak driver current and regenerative-energy handling stay `TBD` until measured stall-current and thermal tests are available.

## 3° uphill turning design point

- Nominal mass 8.463 kg; effective translational mass including shell rotation 9.263 kg.
- Grade 3.0°, longitudinal acceleration 0.20 m/s², speed 0.30 m/s and turn radius 0.80 m.
- Required uphill force 8.68 N; required torque 0.289 N·m per motor; continuous-torque margin 2.07×.
- Wheel/shell traction margin 12.90×; resultant steady lean 4.22° versus a 12.0° contract.
- Inner/outer wheel surface speeds 0.242/0.358 m/s; 2.5g vertical plus 1g lateral head-shock retention margin 2.33×.
- At a 2× continuous-torque margin, the analytical grade ceiling is about 4.50° at zero acceleration and 3.21° while accelerating at 0.20 m/s².

## Checks

- PASS — continuous_torque
- PASS — wheel_shell_traction
- PASS — resultant_lean
- PASS — wheel_speed
- PASS — magnetic_head_combined_shock

## Constraints that remain

- Without a mechanical parking brake, a spherical robot cannot hold position on a slope after power removal; `unpowered_slope_hold=NOT_PROVIDED`.
- Three degrees is an analytical design point, not physical certification. Floor tests still begin level at 0.1 m/s with a wired E-stop and soft barriers.
- Before purchasing the final electronics, measure motor stall current, sealed-shell driver temperature, wheel/shell friction, contactor interruption and emergency stopping distance.

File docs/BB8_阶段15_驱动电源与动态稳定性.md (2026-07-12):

# BB-8 阶段 15：驱动电源与动态稳定性

> 结论：**PASS_ANALYTICAL_ONLY**。阶段15设计点在当前假设下通过，但电机、驱动器、保险丝、接触器、急停、轮壳摩擦与封壳热试验仍全部为`NOT_RUN`。

## 新增的实体结构合同

- Blender新增左右两块52 × 34 × 16 mm通用电机驱动安装包络、双散热器和8枚M3支柱。驱动器型号未冻结。
- 主电源路径显式建模为：电池正极 → 外部可达维护断电 → 主保险丝 → 常开主接触器 → 左右驱动器 → 电机。
- 急停路径显式建模为双通道常闭输入、安全继电器、接触器反馈、手动复位与左右驱动EN；初次试验必须使用有线系留急停，不能只依赖无线。
- 保险丝电流、接触器直流分断能力、驱动器连续/峰值电流和再生吸收能力均保持`TBD`，必须由真实失速电流与热试验冻结。

## 3°上坡 + 转弯设计点

- 名义质量 8.463 kg；含球壳转动惯量的等效平动质量 9.263 kg。
- 坡度 3.0°、纵向加速度 0.20 m/s²、速度 0.30 m/s、转弯半径 0.80 m。
- 需求上坡推进力 8.68 N；每台电机需求 0.289 N·m；连续扭矩裕量 2.07×。
- 轮壳附着裕量 12.90×；合成稳态倾角 4.22°，低于 12.0°合同。
- 左右轮表面速度 0.242/0.358 m/s；磁头2.5g垂向+1g横向冲击合载荷裕量 2.33×。
- 在2×连续扭矩裕量下，0加速度最大解析坡度约 4.50°；保持0.20 m/s²加速时约 3.21°。

## 判定

- PASS — continuous_torque
- PASS — wheel_shell_traction
- PASS — resultant_lean
- PASS — wheel_speed
- PASS — magnetic_head_combined_shock

## 必须保留的限制

- 球形机器人无机械驻车制动时，断电后不能在坡道保持位置；当前`unpowered_slope_hold=NOT_PROVIDED`。
- 3°是解析设计点，不是实物认证。首轮地面试验仍从水平地面、0.1 m/s、有线急停和软围栏开始。
- 真实采购前必须实测电机失速电流、驱动器封壳温升、轮壳摩擦、接触器分断和急停停止距离。

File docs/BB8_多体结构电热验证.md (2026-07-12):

# BB-8 多体、结构与电热验证（阶段 2）

> **PASS WITH DERATING CONSTRAINT**。解析模型要求：低电量时禁止峰值扭矩；结论仍需实物数据和台架验证。

## 转弯与磁头六自由度载荷简化

- 设计点 1.0 m/s、0.6 rad/s，转弯半径 1.67 m，侧向加速度 0.60 m/s²。
- 叠加 1.0g 横向冲击后，头部横向载荷 6.76 N。
- 同时考虑 2.5g 垂向冲击，合载荷 17.31 N；40 N 保持力的合载荷裕量 2.31×。
- 假设横向承载为总保持力的 55%，横向单独裕量 3.25×。

## 磁桅杆弯曲

- 300 mm 长、外径 12 mm、内径 8 mm 铝管悬臂；根部弯矩 2.03 N·m。
- 最大弯曲应力 14.9 MPa；按 276 MPa 屈服强度，静态屈服裕量 18.52×。
- 尚未包含焊缝、孔位、接头间隙、疲劳和共振降额。

## 电机热估算

- 设计扭矩 0.299 N·m/电机，按 0.12 N·m/A 得 2.49 A/电机。
- 绕组铜耗 2.17 W/电机；集总热阻 7 K/W 时稳态温度约 40.2 °C，低于 80 °C 假设限值。

## 4S 电池压降

- 设计点总电流 5.99 A，14.8 V 开路时负载电压 14.50 V。
- 峰值总电流 21.0 A，标称电量负载电压 13.75 V。
- 若开路电压仅 13.6 V，峰值负载电压降至 **12.55 V**，低于 13.2 V 门槛；控制器必须按电池电压降额。

## 硬判定

- PASS — combined_head_retention
- PASS — mast_yield
- PASS — motor_steady_temperature
- PASS — battery_design_voltage
- PASS — battery_peak_nominal_soc

## 下一步实物替换

用实际电机 Kt/电阻/热阻、实测电池内阻、磁保持六方向测力、桅杆材料证书和模态试验替换当前假设。转弯扫描表位于 `engineering/turning_multibody_sweep.csv`。

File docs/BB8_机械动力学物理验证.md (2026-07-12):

# BB-8 机械、动力学与物理学验证（阶段 1：解析模型）

> 结果：**PASS（仅针对当前假设参数）**。这不是实物认证；所有输入都必须由称重、测力、编码器和电流数据替换后重跑。

## 可追溯输入

输入文件：`engineering/physics_inputs.json`。状态：stage-14 mass-ledger assumptions; replace all 17 mass groups with measured hardware values before fabrication approval。

## 设计点结果

- 总质量 8.46 kg，目标速度 1.00 m/s，目标加速度 0.70 m/s²。
- 含球壳转动惯量后的等效质量 9.26 kg；总推进力 8.97 N。
- 每台电机轮端需求 0.299 N·m；0.6 N·m 连续额定裕量 2.01×，1.2 N·m 峰值裕量 4.01×。
- 轮/壳最大静摩擦力 112.0 N；附着裕量 12.48×。
- 设计点机械/电气输入功率估算 12.5 W（未含控制器、待机和冲击峰值）。
- 等效摆体稳态倾角 4.08°；阶段14质量账本给出的名义重心下置 56.2 mm，10°回复力矩 0.81 N·m。
- 头部按 2.5g 冲击载荷 15.9 N；40 N 磁保持裕量 2.51×。

## 判定

- PASS — continuous_motor_torque
- PASS — peak_motor_torque
- PASS — wheel_shell_traction
- PASS — magnetic_head_retention

## 模型覆盖范围与缺口

已覆盖：纯滚动运动学、球壳转动惯量、滚阻、双轮扭矩、轮壳附着、摆体倾角/回复力矩、头部垂向冲击磁保持。

尚未证明：壳体接触有限元、结构疲劳、齿轮热平衡、电池瞬态压降、真实地面滑移、侧向转弯耦合、磁头六自由度稳定性。上述项目必须通过实物参数、台架试验和必要的 FEA/多体动力学继续验证。

## 下一阶段实测门槛

1. 对阶段14的17个质量组逐件称重并测量整机重心；替换当前8.463 kg与56.2 mm模型值。
2. 用拉力计测轮壳静摩擦和弹簧预紧；更新 μ 与每轮法向力。
3. 用扭矩/电流曲线替换 0.6/1.2 N·m 假设，并完成 10 分钟热稳态试验。
4. 用测力计测磁头脱离力；至少在全姿态达到目标冲击载荷的 2×。
5. 轮子架空后再低速落地，记录编码器、IMU、电流、温度和急停响应。

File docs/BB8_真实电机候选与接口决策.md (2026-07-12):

# BB-8 真实电机候选与接口决策（阶段 5）

> 未执行采购。以下结论来自厂家当前产品页和当前解析载荷，用于冻结下一版机械接口。

## 需求

- 96 mm 驱动轮；每电机连续需求 0.299 N·m；目标地速 1.0 m/s。
- 连续扭矩最低设计裕量 2.0×。

## 对比

| 候选 | 厂家工作点 | 96 mm轮理论速度 | 连续扭矩裕量 | 判断 |
|---|---:|---:|---:|---|
| Sha Yang Ye / Cytron IG42E-24K | 248 rpm / 0.980 N·m | 1.25 m/s | 3.28× | 进入阶段5可装配接口 |
| Pololu 4692 30:1 37D 24V encoder | 280 rpm / 0.186 N·m | 1.41 m/s | 0.62× | 不作为当前连续工况首选 |

## 首选接口：IG42E-24K

- 12 V、248 rpm、额定扭矩0.98 N·m、额定电流5.5 A。
- 厂家关联二维图给出：最大外径45 mm、总包络约125.2 mm、8 × 20 mm输出轴、4×M4×6深/PCD35安装孔。
- 图纸重量360 g，但Cytron当前商品页写609 g；结构质量预算继续按609 g保守取值，采购后称重消除冲突。
- 两电机沿310 mm轮距相向安装，中心保留约19.6 mm检修间隙；原150 mm轮距会发生实体重叠，已废弃。
- Cytron 8 mm键毂为26 × 40 mm、3×M5轮端螺纹；M5孔节圆仍标为待实物/专用图纸确认。
- 4S满电16.8 V高于12 V额定值，因此控制器必须按 `12 V / 实时母线电压` 限制PWM；满电最大占空比71.4%。

## 重要差异

Pololu 4692体积和编码器分辨率更好，但厂家最大效率点扭矩仅约0.186 N·m，低于阶段14的0.299 N·m需求。即使其失速外推值较高，也不应把失速值当连续额定值。

## 尚未冻结

编码器尾部连接器、线束弯曲半径、键毂3×M5孔节圆及采购批次公差仍需实物卡尺确认。当前M4电机孔位有厂家图纸依据，M5轮毂孔位仍不可直接下单加工。

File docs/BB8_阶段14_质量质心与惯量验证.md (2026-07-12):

# BB-8 阶段 14：质量、质心与惯量验证

> 结论：**PASS_WITH_MASS_AND_ACCELERATION_DERATING**。新增低位密封配重后，当前假设范围内最不利质心仍在球心下方；所有质量仍须分部称重替换。

## 模型驱动结果

- 名义总质量：**8.463 kg**；输入范围 6.375–10.628 kg。
- 名义质心：x=1.9 mm，y=1.4 mm，z=-56.2 mm。
- 角点穷举质心范围：z=-74.5 至 -27.7 mm；最不利下置量 27.7 mm。
- 质心三轴惯量：Ixx=0.2386、Iyy=0.2703、Izz=0.1085 kg·m²。
- 10°回复力矩 0.81 N·m；俯仰小摆周期 1.51 s。

## 配重与驱动约束

- Blender 新增120 × 70 × 24 mm密封钢配重盒，名义1.50 kg，中央挂板、双束带和4枚M5防松紧固件。
- 在0.6 N·m连续扭矩、2×裕量和当前质量下，最大设计加速度为 **0.703 m/s²**；控制目标冻结为0.70 m/s²。
- 0.70 m/s²等效稳态倾角为 4.08°；原动画±4°只是示意，不是控制限位。
- 若仍强求未经证明的球心下110 mm，还需在z=-220 mm附近额外增加约 **4.14 kg**，会进一步降低加速度裕量，因此取消110 mm作为当前设计事实。

## 判定

- PASS — nominal_com_offset
- PASS — worst_case_com_offset
- PASS — continuous_torque_derated_acceleration

## 证据边界

17个质量组全部标记为`NOT_RUN`或供应商冲突/设计假设。制造前必须逐件称重，并通过悬挂法或四点秤实测整机质心；实测结果须重新生成本报告，不能只接受当前名义值。

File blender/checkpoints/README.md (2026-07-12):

# BB-8 Blender 中间工程

- `BB8_stage01_before_internal_export_fix.blend`：外观面板升级后、内部机构导出回归修复前。
- `BB8_stage02_panel_detail_internal_preserved.blend`：保留 9 个内部机构对象、可关闭 Blender 后重新打开并导出的检查点。
- `BB8_stage03_buildable_internal_assembly.blend`：25 个内部机构对象，加入电机座、四随动轮、桅杆三角支撑、电池固定与电子托盘。
- `BB8_stage04_IG42_contact_geometry.blend`：27个内部对象，按IG42E-24K候选包络重建电机/轴，并让驱动轮及稳定球外缘真实到达508 mm球壳内表面。
- `BB8_stage05_verified_IG42_mount.blend`：45个内部对象；采用125.2 mm电机总包络、310 mm轮距、PCD35电机面板、键毂和紧固件包络，并通过不重叠/球壳内包络审计。
- `BB8_stage06_serviceable_shell_harness.blend`：70个内部对象；加入494 mm赤道密封圈、8个锁扣、12段动力/编码器线束和4个维护连接器，并验证轮子避让与弯曲半径合同。
- `BB8_stage07_magnetic_head_follower.blend`：88个内部对象；加入6+6磁体阵列、8 mm磁隙和3只24 mm头底滚轮，冻结40 N装机拉力验收线。
- `BB8_stage08_unsaved_gui_20260712_183729.blend`：阶段 9.2 结束时 Blender GUI 中带星号的旧内存态；在打开阶段 9.3 新主工程前无损另存，SHA-256 为 `feae71f106221d76f751a086764a18efb1d146b19a03292d65c5384a449a375f`。
- `BB8_stage13_power_safety_hardware.blend`：阶段13首次落盘；板件在帧1冻结世界坐标，已由v2取代，仅作为失败修正证据保留。
- `BB8_stage13_power_safety_hardware_v2.blend`：板件已正确继承内车俯仰；线束对象原点仍在世界零点，已由v3取代。
- `BB8_stage13_power_safety_hardware_v3.blend`：110个内部对象的最终阶段13检查点；双INA226、双2 mΩ Kelvin分流器、6个M2.5支柱、ALERT→EN硬件门和11条保护线均通过重开审计，SHA-256 为 `244acfb60c706770e6bd03c08c76cb9eb8e049152bcd78e71a8b00bc60fa28e7`。
- `BB8_stage14_mass_cg_ballast.blend`：阶段14质量/质心检查点；新增密封1.50 kg低位配重盒及固定结构、17组质量元数据和2个质心标记。后台重开审计为324个总对象、120个内部对象（118制造+2标记），SHA-256 为 `cadd81c99ee3cea6933704de68c6c07e6935c053d063afd77061d3fb11fc1a87`。
- `BB8_stage15_drive_power_estop.blend`：阶段15驱动电源与硬件急停检查点；新增左右通用驱动器、双散热器、8个M3支柱、主保险丝、常开接触器、双通道常闭急停、安全继电器、维护断电、系留急停插口和12条显式电源/安全线。后台重开审计为354个总对象、150个内部对象（147制造+3工程标记），SHA-256 为 `a53d02ab2ffabf14fb747033de267d623f8a41cfb5c5e5d7c5c019c6768f9435`。

阶段16只增加真机遥测与证据审计，不修改几何，也没有新增 `.blend` 检查点。

唯一活动主工程始终位于 `blender/output/BB8_1to1_screen_referenced.blend`。这里的历史检查点仅作阶段证据保留；为遵守“只运行一个Blender工程”的续接规则，后续非几何阶段不再创建新的 `.blend` 副本。

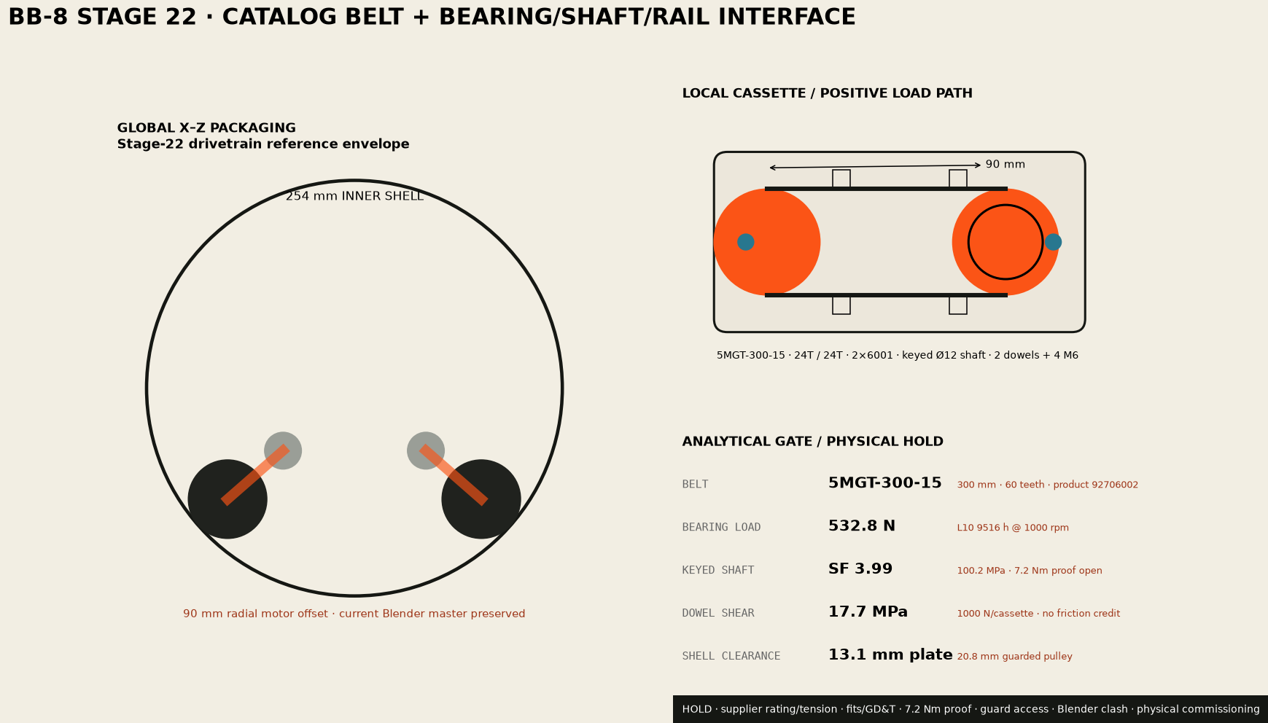
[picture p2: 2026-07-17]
public/images/BB8_stage22_drivetrain_interface.png

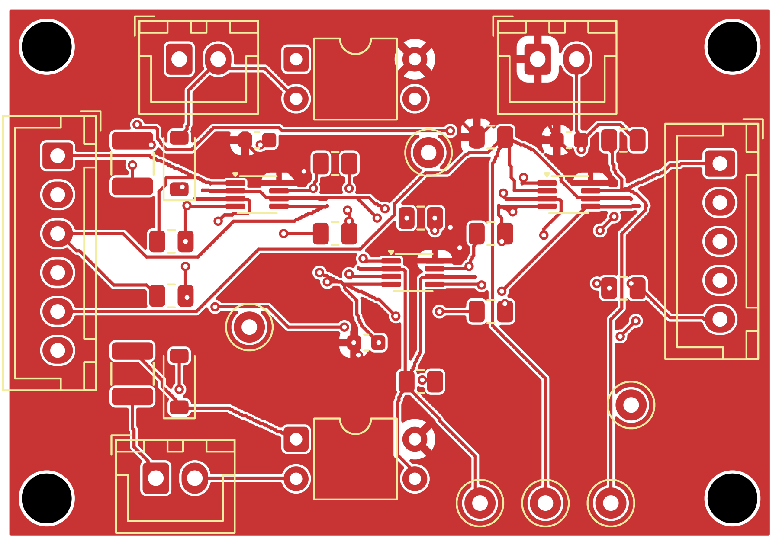
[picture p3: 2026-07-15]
public/images/BB8_stage19_gate_pcb_top.png

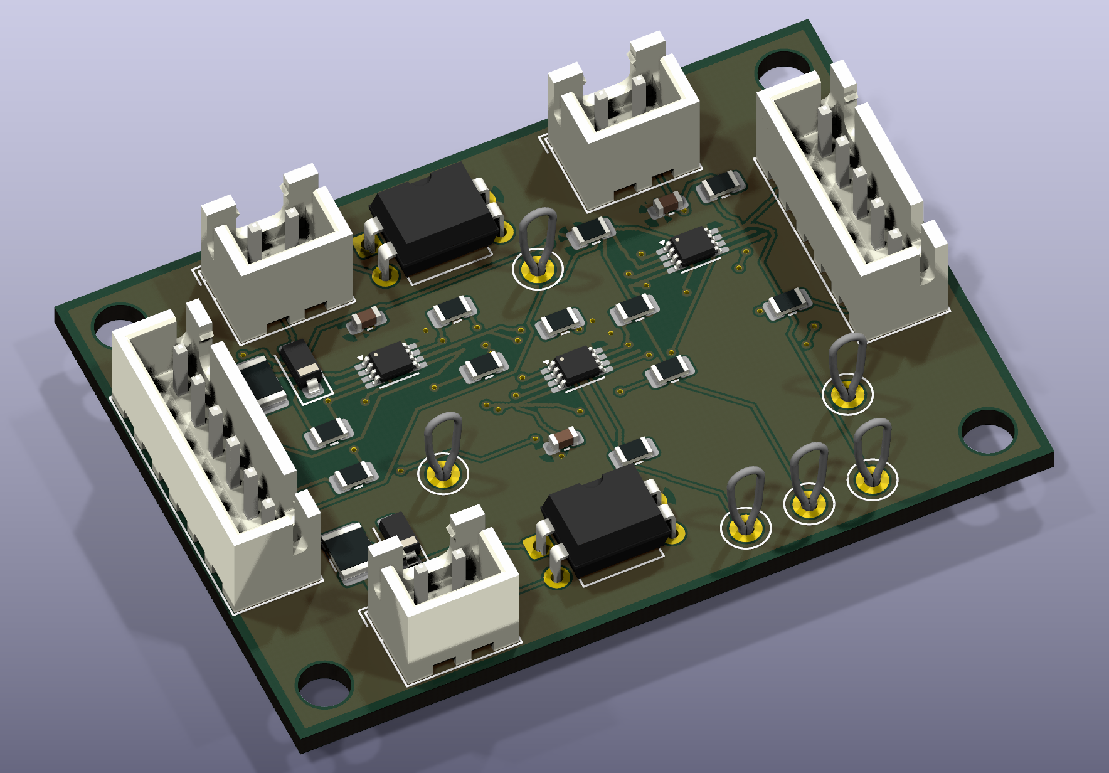
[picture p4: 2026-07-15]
public/images/BB8_stage19_gate_pcb_isometric.png

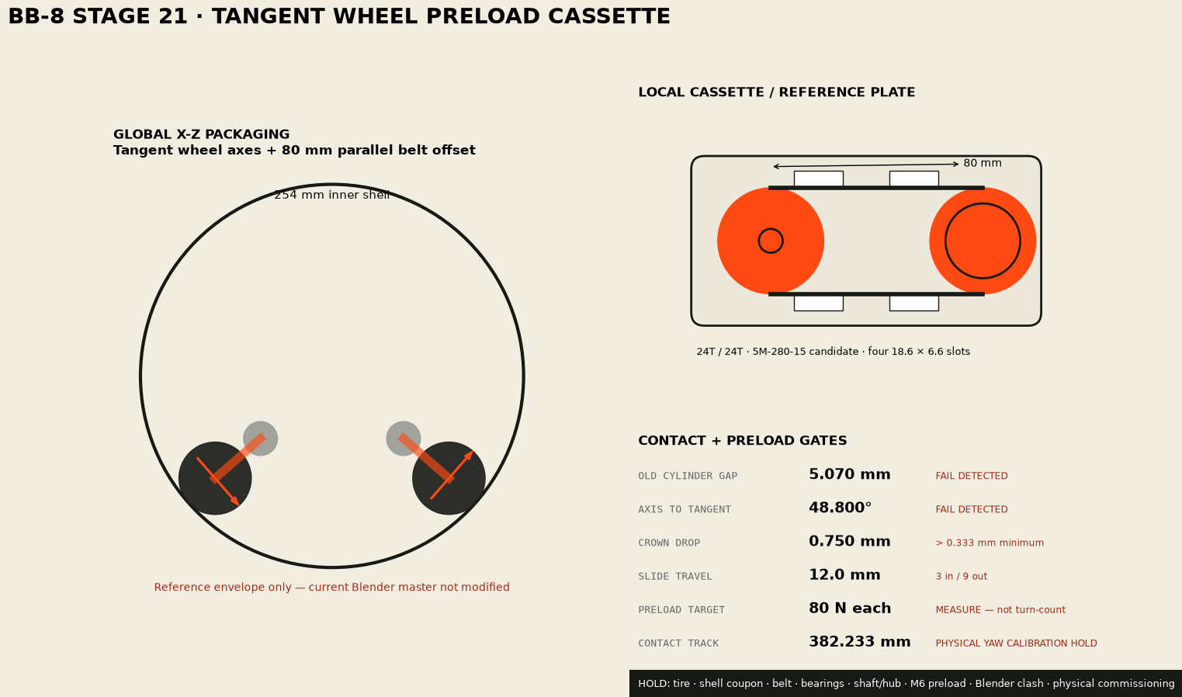
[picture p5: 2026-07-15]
public/images/BB8_stage21_wheel_preload_adjuster.png

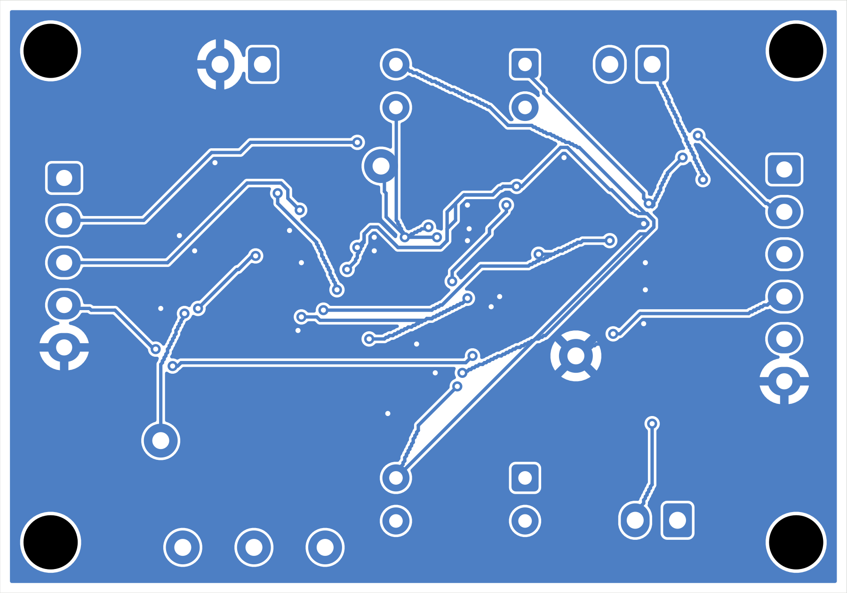
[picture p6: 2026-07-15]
public/images/BB8_stage19_gate_pcb_bottom.png

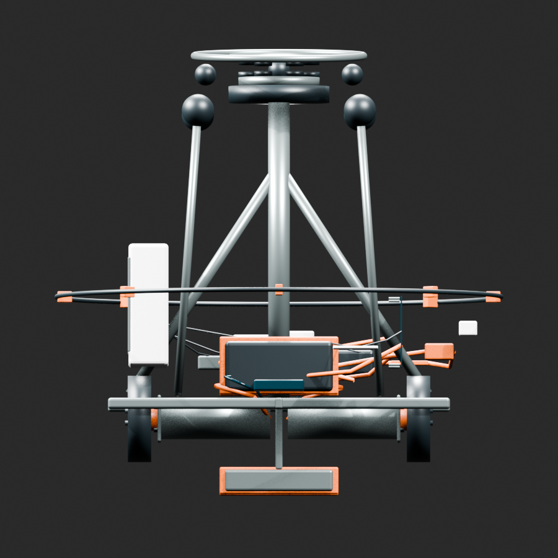
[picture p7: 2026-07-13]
public/model/internal_front.png

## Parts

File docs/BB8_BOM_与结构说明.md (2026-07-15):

# BB-8 1:1 复刻 BOM 与结构说明

> 用途：个人教育/研究原型。这是基于银幕与制作照片的社区复刻方案，不是 Lucasfilm 官方 CAD 或电影道具内部蓝图。

## 1:1 尺寸基准

| 项目 | 尺寸 | 置信度 | 说明 |
|---|---:|---|---|
| 身体球直径 | 508 mm | 中高 | 多个全尺寸制作者的 20 in 基准 |
| 头部最大直径 | 295 mm | 中 | 高清照片比例测量 |
| 头部几何高 | 约 197 mm | 中 | 包含底裙和圆顶 |
| 无天线总高 | 670 mm | 高（总高） | StarWars.com 资料库 0.67 m；拆分尺寸仍为社区测绘 |
| 天线 | 参数化待校准 | 低 | 未找到权威公开尺寸表 |

## 机械 BOM（第一台原型）

| 模块 | 建议规格 | 数量 | 验收要点 |
|---|---|---:|---|
| 球壳 | Ø508 mm 聚碳酸酯/玻璃钢两半球 | 1 套 | 合球后圆度、跳动量和重量一致 |
| 内车主框 | 6061 铝板或碳纤维板 | 1 | 结合阶段14质量账本复算并用实物悬挂/四点秤验证质心 |
| 驱动轮 | 90–100 mm 高摩擦轮 | 2 | 对称、不打滑、可更换轮皮 |
| 减速电机 | 12–24 V、100–200 W、带编码器 | 2 | 左右转速差可标定 |
| 上随动轮 | 尼龙/PU 轮 | 2–4 | 内车始终与球壳保持三点以上接触 |
| 头部耦合 | 封装强磁+防夹隔离结构 | 1 套 | 必须有机械限位和安全拆卸工具 |
| 头底滚轮 | 20–30 mm 低噪声轮 | 3–4 | 旋转不刮伤球壳 |
| 电池 | 4S Li-ion/LiPo，带 BMS/保险丝 | 1 | 固定、防穿刺、易取出 |
| 配重 | 120 × 70 × 24 mm密封钢盒，中央挂板、双束带、4×M5 | 名义1.50 kg | 不可游移；实称后重跑17组质量模型 |

## 当前参数化内部总成（阶段 19）

当前 Blender 工程重开审计确认386个总对象、182个内部对象；其中150个制造对象、9个非制造工程标记和23个阶段19 `non_fabrication_reference` 预 CAD 参考对象，全部带稳定分类标记：

- 两根380 × 18 × 12 mm纵梁和8 × 120 × 12 mm中央横梁，避开两台电机实体包络；
- 两只96 mm驱动轮、两台IG42E候选减速电机、两根8 mm输出轴和两只26 × 40 mm键毂；
- 两块4 mm铝合金电机面板、8枚PCD35上的M4紧固件，以及6枚轮毂M5紧固件包络；
- 494 mm赤道密封圈包络、8个可释放锁扣包络和外观赤道分缝；
- 左右电机动力/编码器线束共12段、4个可断开连接器，以及20/30 mm最低弯曲半径合同；
- 内车侧和头部侧各6个Ø20 × 6 mm磁体包络、8 mm面对面气隙，以及3只Ø24 mm非染色头底滚轮；
- 四只 36 mm 随动稳定轮及四根支撑臂；
- 300 mm 磁桅杆、左右三角支撑和顶部磁载体；
- 4S 电池配重、两条固定带、电子托盘、IMU、保险丝/接触器位置。
- 双34 × 22 × 1.6 mm INA226板、双12 × 5 × 3 mm/2 mΩ Kelvin分流器、6个3 mm高M2.5支柱；阶段13的ALERT→EN占位合同由阶段19的ALERT_N/SAFE_A/SAFE_B→PWM门替代。
- 120 × 70 × 24 mm密封低位配重盒、中央挂板、双束带与4枚M5防松紧固件；名义质量1.50 kg。
- 单块MDD20A官方88.90 × 78.74 mm板框、4枚M3支柱和显式25 mm高度/接线端扫掠假设；器件尚未购买。
- REC Active BMS 4S带壳包络、外部分流器、SW60常开接触器、MIDI保险丝服务空间、50 × 35 × 15 mm双许可PWM门板空间、安全继电器、急停接收器和有线系留急停插口。
- 阶段18新增7条高电流路径与8条安全/反馈路径；两路急停任一开路都必须使接触器释放，并由独立门板撤销MDD20A输入。
- 阶段19新增23个双许可PWM门板、连接器、光耦、逻辑器件、电阻和安装件参考包络；它们只进入设计复核渲染/GLB，不进入150件制造清单或内部机构STL。
- 名义整机8.463 kg、质心z=-56.2 mm；全部最小/最大质量角点穷举后最不利z=-27.7 mm。原110 mm偏置不再作为设计事实。

对象包络、中心坐标和备注自动导出到 `engineering/internal_assembly_manifest.csv`。这些尺寸是装配设计起点，不代表已适配某个实际采购电机；采购后必须以厂家二维图替换电机座、轴孔、紧固件和线束间隙。

## 阶段 5 真实电机安装接口

当前首选设计候选为 Sha Yang Ye / Cytron `IG42E-24K`，尚未购买：

- 12 V、248 rpm、额定扭矩 0.98 N·m、额定电流 5.5 A；
- 厂家关联二维图给出最大外径45 mm、约125.2 mm总包络、8 × 20 mm输出轴、4×M4×6深/PCD35；
- 二维图重量为360 g，而Cytron商品页写609 g；质量预算暂按609 g保守取值，采购后称重；
- 配96 mm轮时额定点理论地速1.25 m/s；阶段14在8.463 kg、0.70 m/s²设计点的连续需求为0.299 N·m，0.98 N·m候选额定扭矩理论裕量3.28×；
- 24:1齿箱长度39.2 mm；两台电机沿310 mm轮距相向安装，中心保留约19.6 mm检修间隙。
- Cytron 8 mm键毂外形26 × 40 mm并提供3×M5轮端螺纹；M5节圆未从当前公开页面确认，因此模型仍明确标记为临时孔位。

模型已把两只驱动轮放到 `R球 - R轮 = 206 mm` 的接触半径，并将四个稳定球放到236 mm接触半径；头底3只滚轮从外侧三点接触254 mm球壳。重新打开审计还会检查两电机不重叠、M4孔节圆、55 mm工具空间、8个锁扣、12段原动力/编码器线束、4个维护连接器、6+6磁体、8 mm磁隙、11条既有电流保护线、阶段18的39个电源舱对象、阶段19的23个预CAD参考对象、配重盒固定和轮子避让。内部对象现为182件，其中150件进入制造STL/CSV、9件仅为工程标记、23件仅为非制造预CAD参考。

## 阶段 7 磁性头部验收门槛

- 头部质量仍按0.65 kg假设；2.5g垂向和1.0g横向合成载荷为17.16 N。
- 按2×安全系数，理论最低保持力34.33 N；工程实测验收线取40 N。
- 40 N必须在实际球壳、实际8 mm总气隙和最不利姿态下由拉力计测得，不能用单块磁体贴合钢板的目录拉力替代。
- 当前未冻结磁体等级、镀层、封装、胶粘剂和拆卸工具；磁体必须机械封装，胶粘剂不可作为唯一防飞出措施。

4S满电16.8 V高于电机12 V额定值，因此固件按 `12 / 实时母线电压` 限制PWM；满电最大占空比71.4%。采购与最终选型仍须用户确认。

## 电控 BOM

- MCU：ESP32-S3 / Teensy 4.1 / STM32 任选一种；建议先以双电机闭环为最小系统。
- IMU：6/9 轴 IMU，刚性安装在内车主框。
- 电机驱动：阶段17首选台架候选为单块双路 Cytron MDD20A（6–30 V、20 A连续/60 A峰值每路、PWM+DIR），但官方接口无独立EN且未明确本应用的再生路径；在外部双通道硬件门与回灌测试完成前不采购冻结。
- 急停：双通道常闭输入、安全继电器、常开主接触器、接触器反馈和手动复位；首次试验必须使用有线系留急停，无线接收机不能单独作为安全链。
- 供电：外部可达维护断电、暂定Littelfuse 30 A MIDI主保险丝、Albright SW60常开接触器候选、5 V/6 V DC-DC 分路；SW60要求辅助反馈和12 V连续线圈，普通续流二极管的35 ms典型释放时间不满足20 ms合同。
- 电池：Molicel P28A 4S2P只作为专业成包候选；4S BMS尚未冻结，散装电芯不得依据本文手工成包。目标BMS至少30 A连续放电、10 A回灌充电、双温度与明确的充放电切断合同。
- 电流监测：左右高侧各1块 INA226，地址0x40/0x41，各配2 mΩ四线分流器；分流脉冲额定必须按实物堵转电流和温升验证。
- 硬件关断：阶段19预CAD合同用SAFE_A、SAFE_B和双INA226 `ALERT_N`三级相与门把左右PWM拉低，同时安全继电器释放常开主接触器；MDD20A的PWM低是制动而非隔离，MCU GPIO不能替代接触器去能。

完整候选、官方来源、裕量和冻结门见[阶段17中文报告](BB8_阶段17_驱动电源器件选型门.md)与[机器可读结果](../engineering/power_component_selection_results.json)。阶段18已用MDD20A官方板框和REC Active BMS 4S目录包络替换两块通用驱动器并通过重开审计；阶段19进一步给出双许可PWM门的64行逻辑、电气计算、正式KiCad原理图、0项违规ERC、BOM、网表、OpenSCAD包络，以及50 × 35 mm两层布线PCB参考设计。PCB机器审计为0项DRC违规、0个未连接项；没有独立原理图/布局同行复核、Gerber/钻孔发布复核、实装板、接插件/线束、热与示波器试验前，仍不能制造或冒充已完成装机。

## 调试门槛

1. 球壳开启、轮子架空：检查方向、编码器和急停。
2. 合球后 10% 功率直行：不加头，用系绳限制活动范围。
3. 验证转向和刹停：电池、配重不得位移。
4. 最后安装磁性头部；每次增速不超过 10%。
5. 平地门全部通过后，才在有线系留急停和软围栏内执行3°仪器坡道试验；当前没有机械驻车制动，断电后不得在坡道停放。

## 安全

- 强磁可造成夹伤并影响心脏起搏器；必须设隔离套和双手安全距离。
- 球体可突然滚动；室内首次调试必须有物理围栏和独立急停。
- LiPo 充电、运输和存储需使用防火袋并遵守电芯厂商要求。

## 尺寸/道具依据

- StarWars.com 制作访谈：https://www.starwars.com/news/droid-dreams-how-neal-scanlan-and-the-star-wars-the-force-awakens-team-brought-bb-8-to-life
- 社区照片测量：https://rimstar.org/science_electronics_projects/bb-8_dimensions.htm
- 公开全尺寸复刻架构：https://makezine.com/projects/open-source-full-sized-bb-8-robot/
- 机械原理推测（网站自述为 best guess）：https://howbb8works.com/

## James Bruton BB-8 V2 公开 CAD/代码镜像

- 原始仓库：https://github.com/XRobots/BB82_public
- 本地核验位置：`third_party/BB82_public`
- 核验提交：`7d73aaed4b95573b5a7ef9a00334302c5549cc7b`
- 内容：约 50 个 Autodesk 123D Design `.123dx` 机械文件，以及主机、遥控器、头部的 Arduino `.ino` 程序。
- 作者项目页明确表述 CAD 和代码“free”，但仓库根目录没有 LICENSE/COPYING。因此本项目仅保留原始 Git 镜像供个人研究，不将其文件混入自制模型、不重新打包发布。
- 作者部件/CAD/代码页：https://www.xrobots.tech/parts-cad-and-code/

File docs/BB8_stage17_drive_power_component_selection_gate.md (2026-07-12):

# BB-8 Stage 17: drive-power component selection gate

> Result: **HOLD_COMPONENT_FREEZE_MEASUREMENTS_REQUIRED**. All 15 official-data-sheet rating screens pass, but this is neither purchase release nor physical validation. Motor stall current, MDD20A regeneration and hard-disable adaptation, fuse I²t, exact contactor ordering/suppression, a compact 4S BMS, professional pack design and all nineteen commissioning gates remain open.

## Deliverables

- `engineering/power_component_candidates.json` separates official ratings, calculations and unknowns.
- `tools/verify_power_component_selection.py` recalculates margins and refuses to treat unresolved items as frozen.
- `engineering/power_component_selection_results.json` is the current machine-readable HOLD result.
- `tests/test_power_component_selection.py` covers the honest HOLD, an undersized driver and the contactor suppression timing boundary.

No purchase, pack fabrication, powered test, stall test or floor run occurred. The Blender master was not changed and no new `.blend` copy was created.

## Candidate matrix

| Module | Candidate | Official rating screen | Current state |
|---|---|---|---|
| Motor | Sha Yang Ye / Cytron IG42E-24K | 12 V, 5.5 A rated, 0.98 N·m, 248 rpm | `HOLD_MEASURE_STALL_CURRENT`; the official page does not publish stall current |
| Dual driver | Cytron MDD20A | 6–30 V; 20 A continuous/60 A peak per channel; 3.3 V PWM/DIR compatible | `HOLD_INTERFACE_AND_REGEN` |
| Main fuse | provisional Littelfuse 498 MIDI 30 A | 32 VDC; typical 2.06 mΩ for the 30 A part | `HOLD_STALL_I2T_CABLE_AND_TEMPERATURE` |
| Main contactor | Albright SW60 SPST-NO with auxiliary contact required | 80 A thermal; 120 A resistive breaking at 48 V | `HOLD_ORDER_CODE_SUPPRESSION_AND_DROP_TEST` |
| Cell/pack | Molicel P28A, professionally built 4S2P candidate | 14.4 V nominal/16.8 V charge; theoretical 70 A discharge | `HOLD_BMS_PACK_SHOP_AND_THERMAL_TEST` |
| BMS | not frozen | 4S, at least 30 A discharge, 10 A regenerative charge, two temperatures and a documented regeneration path | `HOLD_NO_COMPACT_OFFICIAL_4S_CANDIDATE_FROZEN` |

## Analytical margins

Using the Stage-15 total analytical peak of 21 A and the 5.5 A motor rating:

- MDD20A continuous current is **3.64×** motor rated current per channel; its stated peak is **5.71×** the 10.5 A analytical peak per channel; its 30 V limit is **1.79×** the 16.8 V bus maximum.
- The provisional 30 A MIDI fuse is **1.43×** the 21 A analytical peak and its 32 V rating is **1.90×** bus maximum. Stall waveform, harness temperature and I²t coordination can still change the fuse.
- SW60 thermal current is **3.81×** the analytical peak; its 120 A resistive breaking figure at 48 V is **5.71×** that peak.
- A theoretical P28A 4S2P pack provides **3.33×** the analytical peak. Topology-based DC resistance is about 40 mΩ, close to the earlier 50 mΩ analytical assumption.

These figures are catalogue screening only. MDD20A's 60 A peak is a temperature-dependent current limit and the official data sheet does not specify a duration.

## Two interface blockers

### No independent MDD20A enable input

The official interface is dual PWM+DIR, and PWM-low is documented as `Brake`, not electrical isolation. The upstream contactor must therefore remove drive-bus power, and the existing left/right EN contract needs a separately designed and tested dual-channel hardware gate. PWM zero, lost MCU commands and software latches must not be described as hard de-energisation.

### Regenerative path is not frozen

The selected official MDD20A sources do not state regenerative-energy handling for this application. Stage-16 gate P01 must still capture bus peaks during controlled deceleration and E-stop, then prove that driver, BMS and cell charge limits are respected.

## Contactor suppression timing

The SW60 data sheet gives typical release times of 6 ms without suppression, 35 ms with a diode, and 8–20 ms with a diode plus resistor. The system contract is at most 20 ms. A plain flyback diode therefore fails the catalogue-level timing screen. The final clamp must be checked for device ratings and EMC, then measured on the actual coil and bus; this report deliberately does not provide a copy-paste resistor value.

## Geometry boundary

The official MDD20A drawing gives an approximately **88.90 × 78.74 mm** board, **83.82 × 73.66 mm** hole spacing and four Ø3 mm holes. This is substantially larger than the two 52 × 34 × 16 mm generic envelopes currently in Blender, and the official drawing does not freeze height. With BMS, harness and packaging still unresolved, Stage 17 does not force an unverified catalogue envelope into the sole master `.blend`.

## Battery-pack boundary

The P28A sheet states 4.2 V charge, 35 A maximum discharge and 8.4 A maximum charge per cell. It does not authorise hand-built packs from this report. A qualified pack builder must release cell matching, interconnects, insulation, fusing, thermistors, venting, enclosure, connectors, BMS, charger and transport compliance.

The EMUS BMS mini was checked as an official-data reference and rejected because its manual specifies five to sixteen cells. No loose cells should be purchased for pack construction until a suitable 4S BMS and professional pack design are frozen.

## Gates before purchase release

1. Measure startup and controlled-stall current on both actual IG42E motors in a current-limited, wheels-up fixture.
2. Design and bench-test the external dual-channel MDD20A safety gate; E-stop must remove both contactor and control paths.
3. Capture regenerative bus waveforms during deceleration and E-stop.
4. Coordinate fuse I²t and harness temperature against measured waveforms.
5. Freeze the exact non-latching SW60 12 V continuous-coil, auxiliary-contact and suppression configuration; measure release at no more than 20 ms.
6. Freeze a documented 4S BMS and professionally released pack.
7. Pass all nineteen Stage-16 physical evidence gates before removing the system run HOLD.

## Official sources

- Cytron MDD20A: <https://www.cytron.io/p-20amp-6v-30v-dc-motor-driver-2-channels>
- Cytron IG42E-24K: <https://www.cytron.io/p-12v-248rpm-10kgfcm-planetary-dc-geared-motor-with-encoder>
- Littelfuse MIDI 32 V data sheet: <https://www.littelfuse.com/~/media/automotive/datasheets/fuses/passenger-car-and-commercial-vehicle/bolt-down-fuses/littelfuse_midi_datasheet.pdf>
- Albright SW60 data sheet: <https://www.albrightinternational.com/wpcms/wp-content/uploads/2020/08/SW60-Data-Sheet.pdf>
- Molicel INR-18650-P28A data sheet: <https://www.molicel.com/wp-content/uploads/INR18650P28A-V2-80093.pdf>
- EMUS BMS mini manual: <https://emusbms.com/wp-content/uploads/2019/05/EMUS-BMS-mini-User-Manual-v0.9.pdf>

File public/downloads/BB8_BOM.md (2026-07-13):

# BB-8 1:1 复刻 BOM 与结构说明

> 用途：个人教育/研究原型。这是基于银幕与制作照片的社区复刻方案，不是 Lucasfilm 官方 CAD 或电影道具内部蓝图。

## 1:1 尺寸基准

| 项目 | 尺寸 | 置信度 | 说明 |
|---|---:|---|---|
| 身体球直径 | 508 mm | 中高 | 多个全尺寸制作者的 20 in 基准 |
| 头部最大直径 | 295 mm | 中 | 高清照片比例测量 |
| 头部几何高 | 约 197 mm | 中 | 包含底裙和圆顶 |
| 无天线总高 | 670 mm | 高（总高） | StarWars.com 资料库 0.67 m；拆分尺寸仍为社区测绘 |
| 天线 | 参数化待校准 | 低 | 未找到权威公开尺寸表 |

## 机械 BOM（第一台原型）

| 模块 | 建议规格 | 数量 | 验收要点 |
|---|---|---:|---|
| 球壳 | Ø508 mm 聚碳酸酯/玻璃钢两半球 | 1 套 | 合球后圆度、跳动量和重量一致 |
| 内车主框 | 6061 铝板或碳纤维板 | 1 | 结合阶段14质量账本复算并用实物悬挂/四点秤验证质心 |
| 驱动轮 | 90–100 mm 高摩擦轮 | 2 | 对称、不打滑、可更换轮皮 |
| 减速电机 | 12–24 V、100–200 W、带编码器 | 2 | 左右转速差可标定 |
| 上随动轮 | 尼龙/PU 轮 | 2–4 | 内车始终与球壳保持三点以上接触 |
| 头部耦合 | 封装强磁+防夹隔离结构 | 1 套 | 必须有机械限位和安全拆卸工具 |
| 头底滚轮 | 20–30 mm 低噪声轮 | 3–4 | 旋转不刮伤球壳 |
| 电池 | 4S Li-ion/LiPo，带 BMS/保险丝 | 1 | 固定、防穿刺、易取出 |
| 配重 | 120 × 70 × 24 mm密封钢盒，中央挂板、双束带、4×M5 | 名义1.50 kg | 不可游移；实称后重跑17组质量模型 |

## 阶段 18 参数化内部总成

当前 Blender 工程包含150个制造对象和9个非制造工程标记，全部带 `bb8_internal` 稳定标记：

- 两根380 × 18 × 12 mm纵梁和8 × 120 × 12 mm中央横梁，避开两台电机实体包络；
- 两只96 mm驱动轮、两台IG42E候选减速电机、两根8 mm输出轴和两只26 × 40 mm键毂；
- 两块4 mm铝合金电机面板、8枚PCD35上的M4紧固件，以及6枚轮毂M5紧固件包络；
- 494 mm赤道密封圈包络、8个可释放锁扣包络和外观赤道分缝；
- 左右电机动力/编码器线束共12段、4个可断开连接器，以及20/30 mm最低弯曲半径合同；
- 内车侧和头部侧各6个Ø20 × 6 mm磁体包络、8 mm面对面气隙，以及3只Ø24 mm非染色头底滚轮；
- 四只 36 mm 随动稳定轮及四根支撑臂；
- 300 mm 磁桅杆、左右三角支撑和顶部磁载体；
- 4S 电池配重、两条固定带、电子托盘、IMU、保险丝/接触器位置。
- 双34 × 22 × 1.6 mm INA226板、双12 × 5 × 3 mm/2 mΩ Kelvin分流器、6个3 mm高M2.5支柱、独立ALERT→EN门板和11条保护链线束。
- 120 × 70 × 24 mm密封低位配重盒、中央挂板、双束带与4枚M5防松紧固件；名义质量1.50 kg。
- 单块MDD20A官方88.90 × 78.74 mm板框、4枚M3支柱和显式25 mm高度/接线端扫掠假设；器件尚未购买。
- REC Active BMS 4S带壳包络、外部分流器、SW60常开接触器、MIDI保险丝服务空间、双通道独立门板、安全继电器、急停接收器和有线系留急停插口。
- 阶段18新增7条高电流路径与8条安全/反馈路径；两路急停任一开路都必须使接触器释放，并由独立门板撤销MDD20A输入。
- 名义整机8.463 kg、质心z=-56.2 mm；全部最小/最大质量角点穷举后最不利z=-27.7 mm。原110 mm偏置不再作为设计事实。

对象包络、中心坐标和备注自动导出到 `engineering/internal_assembly_manifest.csv`。这些尺寸是装配设计起点，不代表已适配某个实际采购电机；采购后必须以厂家二维图替换电机座、轴孔、紧固件和线束间隙。

## 阶段 5 真实电机安装接口

当前首选设计候选为 Sha Yang Ye / Cytron `IG42E-24K`，尚未购买：

- 12 V、248 rpm、额定扭矩 0.98 N·m、额定电流 5.5 A；
- 厂家关联二维图给出最大外径45 mm、约125.2 mm总包络、8 × 20 mm输出轴、4×M4×6深/PCD35；
- 二维图重量为360 g，而Cytron商品页写609 g；质量预算暂按609 g保守取值，采购后称重；
- 配96 mm轮时额定点理论地速1.25 m/s；阶段14在8.463 kg、0.70 m/s²设计点的连续需求为0.299 N·m，0.98 N·m候选额定扭矩理论裕量3.28×；
- 24:1齿箱长度39.2 mm；两台电机沿310 mm轮距相向安装，中心保留约19.6 mm检修间隙。
- Cytron 8 mm键毂外形26 × 40 mm并提供3×M5轮端螺纹；M5节圆未从当前公开页面确认，因此模型仍明确标记为临时孔位。

模型已把两只驱动轮放到 `R球 - R轮 = 206 mm` 的接触半径，并将四个稳定球放到236 mm接触半径；头底3只滚轮从外侧三点接触254 mm球壳。重新打开审计还会检查两电机不重叠、M4孔节圆、55 mm工具空间、8个锁扣、12段原动力/编码器线束、4个维护连接器、6+6磁体、8 mm磁隙、11条既有电流保护线、阶段18的39个电源舱对象、配重盒固定和轮子避让。内部对象现为159件，其中150件进入制造STL/CSV、9件仅为工程标记。

## 阶段 7 磁性头部验收门槛

- 头部质量仍按0.65 kg假设；2.5g垂向和1.0g横向合成载荷为17.16 N。
- 按2×安全系数，理论最低保持力34.33 N；工程实测验收线取40 N。
- 40 N必须在实际球壳、实际8 mm总气隙和最不利姿态下由拉力计测得，不能用单块磁体贴合钢板的目录拉力替代。
- 当前未冻结磁体等级、镀层、封装、胶粘剂和拆卸工具；磁体必须机械封装，胶粘剂不可作为唯一防飞出措施。

4S满电16.8 V高于电机12 V额定值，因此固件按 `12 / 实时母线电压` 限制PWM；满电最大占空比71.4%。采购与最终选型仍须用户确认。

## 电控 BOM

- MCU：ESP32-S3 / Teensy 4.1 / STM32 任选一种；建议先以双电机闭环为最小系统。
- IMU：6/9 轴 IMU，刚性安装在内车主框。
- 电机驱动：阶段17首选台架候选为单块双路 Cytron MDD20A（6–30 V、20 A连续/60 A峰值每路、PWM+DIR），但官方接口无独立EN且未明确本应用的再生路径；在外部双通道硬件门与回灌测试完成前不采购冻结。
- 急停：双通道常闭输入、安全继电器、常开主接触器、接触器反馈和手动复位；首次试验必须使用有线系留急停，无线接收机不能单独作为安全链。
- 供电：外部可达维护断电、暂定Littelfuse 30 A MIDI主保险丝、Albright SW60常开接触器候选、5 V/6 V DC-DC 分路；SW60要求辅助反馈和12 V连续线圈，普通续流二极管的35 ms典型释放时间不满足20 ms合同。
- 电池：Molicel P28A 4S2P只作为专业成包候选；4S BMS尚未冻结，散装电芯不得依据本文手工成包。目标BMS至少30 A连续放电、10 A回灌充电、双温度与明确的充放电切断合同。
- 电流监测：左右高侧各1块 INA226，地址0x40/0x41，各配2 mΩ四线分流器；分流脉冲额定必须按实物堵转电流和温升验证。
- 硬件关断：两路开漏 ALERT 和双通道急停必须门控外部安全逻辑并释放主接触器；MDD20A的PWM低是制动而非隔离，MCU GPIO不能替代独立硬件去能。

完整候选、官方来源、裕量和冻结门见[阶段17中文报告](BB8_阶段17_驱动电源器件选型门.md)与[机器可读结果](../engineering/power_component_selection_results.json)。阶段18已用MDD20A官方88.90 × 78.74 mm板框和REC Active BMS 4S目录包络替换两块通用驱动器，并通过重开审计；在样品孔位、接插件、线束和热试验完成前，仍不能把解析几何冒充成已完成装机。

## 调试门槛

1. 球壳开启、轮子架空：检查方向、编码器和急停。
2. 合球后 10% 功率直行：不加头，用系绳限制活动范围。
3. 验证转向和刹停：电池、配重不得位移。
4. 最后安装磁性头部；每次增速不超过 10%。
5. 平地门全部通过后，才在有线系留急停和软围栏内执行3°仪器坡道试验；当前没有机械驻车制动，断电后不得在坡道停放。

## 安全

- 强磁可造成夹伤并影响心脏起搏器；必须设隔离套和双手安全距离。
- 球体可突然滚动；室内首次调试必须有物理围栏和独立急停。
- LiPo 充电、运输和存储需使用防火袋并遵守电芯厂商要求。

## 尺寸/道具依据

- StarWars.com 制作访谈：https://www.starwars.com/news/droid-dreams-how-neal-scanlan-and-the-star-wars-the-force-awakens-team-brought-bb-8-to-life
- 社区照片测量：https://rimstar.org/science_electronics_projects/bb-8_dimensions.htm
- 公开全尺寸复刻架构：https://makezine.com/projects/open-source-full-sized-bb-8-robot/
- 机械原理推测（网站自述为 best guess）：https://howbb8works.com/

## James Bruton BB-8 V2 公开 CAD/代码镜像

- 原始仓库：https://github.com/XRobots/BB82_public
- 本地核验位置：`third_party/BB82_public`
- 核验提交：`7d73aaed4b95573b5a7ef9a00334302c5549cc7b`
- 内容：约 50 个 Autodesk 123D Design `.123dx` 机械文件，以及主机、遥控器、头部的 Arduino `.ino` 程序。
- 作者项目页明确表述 CAD 和代码“free”，但仓库根目录没有 LICENSE/COPYING。因此本项目仅保留原始 Git 镜像供个人研究，不将其文件混入自制模型、不重新打包发布。
- 作者部件/CAD/代码页：https://www.xrobots.tech/parts-cad-and-code/

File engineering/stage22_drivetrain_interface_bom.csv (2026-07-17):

item | qty_robot | category | description | candidate_spec | status
S22-001 | 2 | belt | Gates Poly Chain GT Carbon belt | 5MGT-300-15, product 92706002, 300 mm, 60T, 15 mm | CATALOG_IDENTIFIED_HOLD_POWER_RATING_TENSION
S22-002 | 2 | motor pulley | 24T 5MGT 15 mm pulley | P24-5MGT-15-MPB family, finish-bore to verified 8 mm motor shaft | HOLD_BORE_KEY_OR_CLAMP_RETENTION
S22-003 | 2 | wheel pulley | 24T 5MGT 15 mm removable pulley | P24-5MGT-15-MPB family, 12 mm keyed bore | HOLD_BORE_KEY_AXIAL_RETENTION
S22-004 | 4 | bearing | sealed 6001 wheel-shaft bearing | 12x28x8 mm; C>=4.42 kN, C0>=2.36 kN | HOLD_SUPPLIER_CLEARANCE_SEAL_FITS
S22-005 | 2 | shaft | 12 mm keyed wheel shaft | certified yield >=400 MPa; keyway factored screen | HOLD_MATERIAL_CERT_DRAWING_FATIGUE
S22-006 | 4 | key | wheel and pulley parallel keys | DIN 6885 candidate 4x4x20 mm minimum engagement | HOLD_FIT_AND_7P2NM_TORQUE_PROOF
S22-007 | 2 | wheel hub | keyed wheel hub with positive axial retention | 20 mm minimum keyed engagement | HOLD_HUB_DRAWING_AND_TORQUE_PROOF
S22-008 | 2 | bearing retainer | outboard bolted bearing retainer | reference DXF; shoulder and fasteners TBD | HOLD_FIT_GDT_ENDPLAY
S22-009 | 2 | floating housing | inboard floating-bearing housing | >=0.3 mm axial float, anti-creep validation | HOLD_PHYSICAL_ENDPLAY_ANTICREEP
S22-010 | 4 | dowel | rail-interface locating dowel | 6 mm, two per cassette, reamed fit | HOLD_MATERIAL_REAM_GDT
S22-011 | 8 | clamp | rail-interface M6 clamp bolt | four per cassette; not credited for shear strength | HOLD_GRADE_PRELOAD_LOCKING
S22-012 | 2 | hard stop | positive cassette radial hard stop | reacts jackscrew and shock load into rail bridge | HOLD_RAIL_INTEGRATION
S22-013 | 2 | guard | removable belt and pulley guard | 3 mm reference envelope; power-isolated service only | HOLD_MATERIAL_FASTENERS_ACCESS
S22-014 | 2 | test | keyed-joint torque-proof fixture | 7.2 N m proof without slip or permanent set | REQUIRED_BEFORE_RELEASE

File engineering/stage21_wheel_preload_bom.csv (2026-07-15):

item | qty_robot | category | description | candidate_spec | status
S21-001 | 4 | machined plate | 6 mm moving cassette side plate | 6061-T6/T651; reference DXF/STL | HOLD_MATERIAL_FIT_GDT
S21-002 | 4 | machined plate | 6 mm fixed radial-slider plate with 4 M6 slots per cassette | 6061-T6/T651; 18.6 x 6.6 mm reference slots | HOLD_MATERIAL_FIT_GDT
S21-003 | 2 | wheel | 96 x 26 mm crowned drive wheel | 0.75 mm axial crown drop; TPU or cast polyurethane | HOLD_DUROMETER_BOND_WEAR
S21-004 | 2 | shaft | 12 mm wheel shaft with retained hub | material keyway and retention TBD | HOLD_SHAFT_HUB_FATIGUE
S21-005 | 4 | bearing | sealed wheel-shaft bearing | 6001-2RS 12 x 28 x 8 mm candidate | HOLD_FIT_LIFE_SUPPLIER
S21-006 | 2 | belt | HTD-style synchronous belt | 5M-280-15; 56 teeth | HOLD_RATING_TENSION_GUARD
S21-007 | 2 | pulley | 24T motor pulley | 5 mm pitch; 15 mm width; 8 mm motor bore | HOLD_VENDOR_BORE_RETENTION
S21-008 | 2 | pulley | 24T wheel pulley | 5 mm pitch; 15 mm width; 12 mm wheel bore | HOLD_VENDOR_BORE_RETENTION
S21-009 | 8 | clamp | M6 cassette clamp bolt with washer and locking feature | grade preload and locking TBD | HOLD_GRADE_PRELOAD_FRICTION
S21-010 | 2 | adjuster | M6x1 preload jackscrew with jam nut | hard stops required; 12 mm usable travel | HOLD_THREAD_SUPPORT_FORCE_CALIBRATION
S21-011 | 2 | guard | belt and pinch-point guard | remove only with power isolated | HOLD_FINAL_ENVELOPE
S21-012 | 2 | measurement | temporary radial force-gauge fixture | 60-100 N setup band; 10 N left-right match | REQUIRED_BEFORE_CONTACT_FREEZE

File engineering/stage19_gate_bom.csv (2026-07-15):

reference | quantity | category | manufacturer | part_number | value_or_package | release_status | official_source | note
PCB1 | 1 | pcb | TBD | CUSTOM_STAGE19_GATE | 50x35x1.6 mm 2-layer FR-4 | ROUTED_DRC_REFERENCE_ONLY_NOT_RELEASED_FOR_FABRICATION |  | Four 3.2 mm NPTH mounting holes at the contracted 3/47 x 3/32 mm centres; fabrication prohibited until independent peer review and intentional Gerber/drill release review
U1 U2 | 2 | optocoupler | Vishay | VO617A-4 | DIP-4 | REFERENCE_SELECTED | https://www.vishay.com/docs/83430/vo617a.pdf | CTR bin 160-320% only specified at IF=5 mA VCE=5 V and 25 C
U3 U4 U5 | 3 | logic | Texas Instruments | SN74LVC2G08DCU | VSSOP-8 | REFERENCE_SELECTED | https://www.ti.com/lit/ds/symlink/sn74lvc2g08.pdf | One dual gate package per permissive stage
R1 R2 | 2 | resistor | TBD | TBD | 2.00 kOhm 1% 0.5 W | VALUE_FROZEN_PART_TBD |  | Safety-loop LED current limit
R3 R4 | 2 | resistor | TBD | TBD | 4.70 kOhm 1% >=0.1 W | VALUE_FROZEN_PART_TBD |  | SAFE_A_OK and SAFE_B_OK emitter pull-down
R5 R6 | 2 | resistor | TBD | TBD | 10.0 kOhm 1% >=0.1 W | VALUE_FROZEN_PART_TBD |  | MCU PWM input pull-down
R7 R8 | 2 | resistor | TBD | TBD | 10.0 kOhm 1% >=0.1 W | VALUE_FROZEN_PART_TBD |  | U3 intermediate pull-down
R9 R10 | 2 | resistor | TBD | TBD | 10.0 kOhm 1% >=0.1 W | VALUE_FROZEN_PART_TBD |  | U4 intermediate pull-down
R11 R12 | 2 | resistor | TBD | TBD | 10.0 kOhm 1% >=0.1 W | VALUE_FROZEN_PART_TBD |  | Final MDD20A PWM output fail-low pull-down
R13 | 1 | resistor | TBD | TBD | 10.0 kOhm 1% >=0.1 W | VALUE_FROZEN_PART_TBD |  | ALERT_N pull-up; open ALERT wiring is not fail-safe
C1 C2 C3 | 3 | capacitor | TBD | TBD | 100 nF X7R >=10 V | VALUE_FROZEN_PART_TBD |  | One local decoupler per LVC package
D1 D2 | 2 | diode | TBD | 1N4148W | SOD-123 | REFERENCE_SELECTED_PART_VENDOR_TBD |  | Anti-parallel reverse clamp for each optocoupler LED
J1 J4 J5 | 3 | connector | JST | B2B-XH-A | 2-position 2.5 mm top-entry | REFERENCE_SELECTED | https://www.jst-mfg.com/product/pdf/eng/eXH.pdf | Logic power and independent safety inputs
J2 | 1 | connector | JST | B6B-XH-A | 6-position 2.5 mm top-entry | REFERENCE_SELECTED | https://www.jst-mfg.com/product/pdf/eng/eXH.pdf | MCU PWM DIR ALERT_N and GND
J3 | 1 | connector | JST | B5B-XH-A | 5-position 2.5 mm top-entry | REFERENCE_SELECTED | https://www.jst-mfg.com/product/pdf/eng/eXH.pdf | MDD20A PWM DIR and GND
TP1 TP2 TP3 TP4 TP5 TP6 | 6 | test_point | TBD | TBD | 1.0 mm loop or pad | FOOTPRINT_TBD |  | SAFE_A_OK SAFE_B_OK ALERT_N PWM_L_OUT PWM_R_OUT and GND
H1 H2 H3 H4 | 4 | mounting | TBD | TBD | M3 insulated standoff hardware | MECHANICAL_CANDIDATE |  | Keep conductive hardware clear of logic and isolated input copper

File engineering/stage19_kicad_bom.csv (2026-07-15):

Refs | Value | Footprint | Qty | DNP
C1 | 100nF X7R 10V MIN | Capacitor_SMD:C_0603_1608Metric | 1
C2 | 100nF X7R 10V MIN | Capacitor_SMD:C_0603_1608Metric | 1
C3 | 100nF X7R 10V MIN | Capacitor_SMD:C_0603_1608Metric | 1
D1 | 1N4148W REVERSE CLAMP | Diode_SMD:D_SOD-123 | 1
D2 | 1N4148W REVERSE CLAMP | Diode_SMD:D_SOD-123 | 1
J1 | B2B-XH-A / LOGIC POWER | Connector_JST:JST_XH_B2B-XH-A_1x02_P2.50mm_Vertical | 1
J2 | B6B-XH-A / MCU+ALERT | Connector_JST:JST_XH_B6B-XH-A_1x06_P2.50mm_Vertical | 1
J3 | B5B-XH-A / MDD20A | Connector_JST:JST_XH_B5B-XH-A_1x05_P2.50mm_Vertical | 1
J4 | B2B-XH-A / SAFE A | Connector_JST:JST_XH_B2B-XH-A_1x02_P2.50mm_Vertical | 1
J5 | B2B-XH-A / SAFE B | Connector_JST:JST_XH_B2B-XH-A_1x02_P2.50mm_Vertical | 1
R1 | 2.00k 1% 0.5W MIN | Resistor_SMD:R_1210_3225Metric | 1
R2 | 2.00k 1% 0.5W MIN | Resistor_SMD:R_1210_3225Metric | 1
R3 | 4.70k 1% | Resistor_SMD:R_0805_2012Metric | 1
R4 | 4.70k 1% | Resistor_SMD:R_0805_2012Metric | 1
R5 | 10.0k 1% | Resistor_SMD:R_0805_2012Metric | 1
R6 | 10.0k 1% | Resistor_SMD:R_0805_2012Metric | 1
R7 | 10.0k 1% | Resistor_SMD:R_0805_2012Metric | 1
R8 | 10.0k 1% | Resistor_SMD:R_0805_2012Metric | 1
R9 | 10.0k 1% | Resistor_SMD:R_0805_2012Metric | 1
R10 | 10.0k 1% | Resistor_SMD:R_0805_2012Metric | 1
R11 | 10.0k 1% | Resistor_SMD:R_0805_2012Metric | 1
R12 | 10.0k 1% | Resistor_SMD:R_0805_2012Metric | 1
R13 | 10.0k 1% | Resistor_SMD:R_0805_2012Metric | 1
TP1 | SAFE_A_OK | TestPoint:TestPoint_Loop_D2.50mm_Drill1.0mm | 1
TP2 | SAFE_B_OK | TestPoint:TestPoint_Loop_D2.50mm_Drill1.0mm | 1
TP3 | ALERT_N | TestPoint:TestPoint_Loop_D2.50mm_Drill1.0mm | 1
TP4 | PWM_L_OUT | TestPoint:TestPoint_Loop_D2.50mm_Drill1.0mm | 1
TP5 | PWM_R_OUT | TestPoint:TestPoint_Loop_D2.50mm_Drill1.0mm | 1
TP6 | GND | TestPoint:TestPoint_Loop_D2.50mm_Drill1.0mm | 1
U1 | VO617A-4 | Package_DIP:DIP-4_W7.62mm | 1
U2 | VO617A-4 | Package_DIP:DIP-4_W7.62mm | 1
U3 | SN74LVC2G08DCU | Package_SO:VSSOP-8_2.3x2mm_P0.5mm | 1
U4 | SN74LVC2G08DCU | Package_SO:VSSOP-8_2.3x2mm_P0.5mm | 1
U5 | SN74LVC2G08DCU | Package_SO:VSSOP-8_2.3x2mm_P0.5mm | 1

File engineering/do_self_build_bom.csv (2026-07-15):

item_id | subsystem | qty | procurement_state | component | source_spec | current_decision | verification_gate | license_boundary | notes
D001 | mechanical | 1 | BLOCKED | D-O functional mechanical package | Baddeley Patreon V2; Denton V1 free WIP; JRIZZ Cults paid WIP | Select a route only after licence provenance archive completeness and revision are recorded | Denton: audit missing head/STEP and provenance; paid routes: require explicit purchase confirmation and exact file inventory | Free listing or paid access does not by itself prove a complete openly redistributable package | Static Printables and Gambody articulation files are reference-only and cannot replace a driveable package
D002 | mechanical | 1 | REFERENCE_ONLY | 60 mm wheel-off test stand | Public STL from Printed Droid | Use only as a local bench aid if its terms are acceptable | Confirm dimensions fit the chosen chassis and do not redistribute | No explicit redistribution license found | Not a complete robot model
D003 | mechanical | 1 | BLOCKED | Complete fastener bearing shaft and printed-part set | Not fully specified in the public control repository | Freeze only after the licensed CAD package and assembly guide are reconciled | Generate a drawing-derived fastener and bearing count | Depends on the purchased mechanical package | Do not purchase bulk hardware from video estimates alone
D010 | control | 1 | READY_TO_SOURCE | Arduino Mega 2560 | v3.4.3 requires a Mega and Serial1 for iBus | Use a genuine or electrically compatible Mega 2560 | Compile and upload the pinned v3.4.3 sketch | Controller source is personal non-commercial with notice retention | Current local compile gate passes
D011 | motor_control | TBD | HOLD_CONFLICT | Cytron motor driver | Root README says one MDD10A dual-channel while v3.4 README says two MD10C | Do not buy until board architecture and motor peak current are frozen | Confirm PWM DIR compatibility voltage continuous current peak current thermal path and fuse rating | Product hardware terms apply separately from firmware | The public source is internally inconsistent
D012 | sensing | 1 | READY_TO_SOURCE | MPU6050-compatible IMU | MPU6050 MPU6500 MPU9250 or MPU6886 at I2C 0x68 or 0x69 | Prefer one known-good module with documented logic voltage | Pass WHO_AM_I axis test calibration and 400 kHz I2C run | Module vendor terms apply | Wire Mega D20 SDA and D21 SCL
D013 | radio | 1 | READY_TO_SOURCE | 10-channel iBus receiver | v3.4 recommends FS-RX2A Pro and warns FS-iA6B exposes only 6 channels | Use a receiver that exposes all 10 control channels over iBus | Menu t must show SIGNAL OK and every mapped channel | Radio compliance and product terms apply | iBus signal enters Mega D19 and requires common ground
D014 | radio | 1 | READY_TO_SOURCE | Compatible RC transmitter | Default map consumes channels 1 through 10 | Use a transmitter that can operate the receiver in 10-channel mode | Record failsafe behavior and complete menu p mapping | Product terms apply | Keep a physical power cut-off even when software failsafe is configured
D015 | audio | 1 | READY_TO_SOURCE | DFPlayer Mini | v3.4 drives it from Mega D7 and D8 | Use with a FAT16 or FAT32 microSD | Pass startup playback volume and brownout tests | Module terms apply | Sound files are not included and must be lawfully sourced
D016 | audio | 1 | READY_TO_SOURCE | MicroSD card | Repository requires FAT16 or FAT32 and four-digit filenames | Small reliable card formatted FAT32 | Verify 0001.mp3 through 0032.mp3 address correctly | Audio copyright remains separate | Copy order is irrelevant in v3.4.3
D017 | audio | 1 | READY_TO_SOURCE | Speaker | Repository states 8 ohm below 3 W | Select only after enclosure volume and desired loudness are known | Check distortion module temperature and supply noise | Product terms apply | Do not exceed the DFPlayer output capability
D018 | actuation | 4 | HOLD_LOAD_UNKNOWN | Mainbar and head servos | Repository says four standard servos and also says SG90 or similar | Do not freeze model until required torque speed travel and packaging are measured | Measure static and dynamic load then require at least 2x torque margin | Product terms apply | The wording standard servo versus SG90 micro-servo is not a dependable mechanical specification
D019 | actuation | 2 | HOLD_LOAD_UNKNOWN | Drive motors and gearboxes | Exact motor model ratio encoder and stall current are absent from the public repository | Select only after wheel diameter mass center of gravity and target acceleration are known | Measure no-load current stall current wheel torque speed and thermal rise | Product terms apply | The README current figures are source claims and not a safe motor selection basis
D020 | power | 2 | PROVISIONAL | 2S LiPo packs in series | Repository states 4S total 16.8 V full 14.8 V nominal and 12.0 V empty | Use only after the motor and regulator voltage limits are confirmed | Capacity C-rating connector and fuse must pass measured peak-current test | Battery vendor and transport rules apply | Never series-connect unmatched state-of-charge packs
D021 | power | 1 | ENGINEERING_REQUIRED | 5 to 6 V servo BEC or regulator | Not fully specified by the repository | Specify from simultaneous servo stall current plus margin | Verify rail stays within servo limits during all four-servo motion | Product terms apply | Do not power four servos from the Mega 5 V pin
D022 | power | 1 | ENGINEERING_REQUIRED | Logic power regulator | Repository states Mega 7 to 12 V but the battery is 4S | Use a regulator or approved input path that never applies 16.8 V to a 12 V-rated rail | Test full-charge input startup ripple temperature and brownout recovery | Product terms apply | The final architecture depends on the purchased control board
D023 | power | 1 | ENGINEERING_REQUIRED | Main fuse master switch and emergency disconnect | Repository requires appropriate motor fuses and immediate power-cut capability | Place a reachable hardware disconnect and branch protection near the battery | Prove zero motor output after activation under worst-case load | Product terms apply | Software stop is not the sole emergency stop
D024 | power | 1 | READY_TO_SOURCE | Battery voltage divider | 10 kOhm high side plus 3.3 kOhm low side to A15 | Use measured precision resistors and calibrate in firmware | Compare A15 reading with a calibrated meter at full and low voltage | Component terms apply | Enable battery monitoring only after the divider is connected
D025 | signal | 1 | READY_TO_SOURCE | DFPlayer series resistor | Optional 1 kOhm resistor on the DFPlayer serial line | Fit during bench wiring unless the selected module documents otherwise | Verify reliable playback without serial corruption | Component terms apply | Repository labels this recommended
D026 | power | 1 | READY_TO_SOURCE | Input decoupling capacitor | Optional 100 uF capacitor on battery input | Fit near the affected electronics with correct voltage and polarity rating | Check supply ripple and temperature during motor steps | Component terms apply | Value is a starting point rather than a complete EMC design
D027 | wiring | 1 | ENGINEERING_REQUIRED | Wiring connectors strain relief and common grounds | Pin map is public but harness lengths and connector family are not | Create a labelled serviceable harness after the chassis is frozen | Continuity polarity pull-test bend-radius and moving-part clearance gates | Product terms apply | No hot-plugging while energized
D028 | safety | 1 | ENGINEERING_REQUIRED | Wheel-off cradle tether and clear test area | Repository warns about moving parts and supervised operation | Use a cradle for first motor tests and a tether for first balance tests | Operator can cut power without entering the wheel envelope | Local workshop rules apply | Secure the head before balance testing
D029 | thermal | 1 | ENGINEERING_REQUIRED | Driver and regulator ventilation or heatsinking | Repository requires adequate motor-driver ventilation | Design after measured losses and enclosure airflow are known | Run a timed worst-case thermal soak below component ratings | Product terms apply | No temperature claim is accepted from an open-air bench test alone
D030 | firmware | 1 | READY_LOCAL | v3.4.3 Arduino firmware | Pinned commit e90aacd and local Mega compile proof | Use D-O_ibus_v3.4/D_O_printed_droid_rc_ibus_v3.4.3.ino | Recompile then record uploaded hash configuration and EEPROM map | Personal non-commercial license with notice and attribution | Flash 17 percent and RAM 18 percent prove compilation only
D031 | signal | 4 | SOFTWARE_REMAP_READY_HOLD_PHYSICAL_CONTINUITY | Four servo outputs remapped away from Mega D0 RX0 and D1 TX0 | The deterministic v3.4.3 safe-pin transformer assigns mainbar/head1/head2/head3 to D22/D23/D24/D25 and preserves Serial0 | Build the safe-pin variant only from pinned commit e90aacd and source SHA-256 6cb3ce0d; do not connect actuator power until continuity and pulse tests pass | Logic-analyser proof of D22-D25 servo pulse width plus USB upload reset 9600 baud RX/TX menu integrity four-servo motion and failsafe | Arduino pin mapping is CC BY-SA; upstream firmware remains personal non-commercial and transformed source is not republished | Software collision is removed in the compiled variant but physical wiring and powered behavior remain NOT_RUN
D032 | signal | 1 | VARIANT_WIRING_GENERATED_HOLD_CONTINUITY | Version-locked safe-pin wiring contract | Generated contract binds D22-D25 to transformed source SHA-256 f858c485 and releases D0/D1 for Serial0 | Use engineering/do_safe_pin_variant_wiring.csv and compile evidence together; reject generic v2.1 or unpatched v3.4.3 diagrams | Continuity-test all four servo nets confirm the transformed source SHA-256 then prove USB menu and pulse behavior before actuator power | Reference-page terms apply and the firmware remains personal non-commercial | The wiring document now exists but flash and actuator-power release remain false until real bench evidence

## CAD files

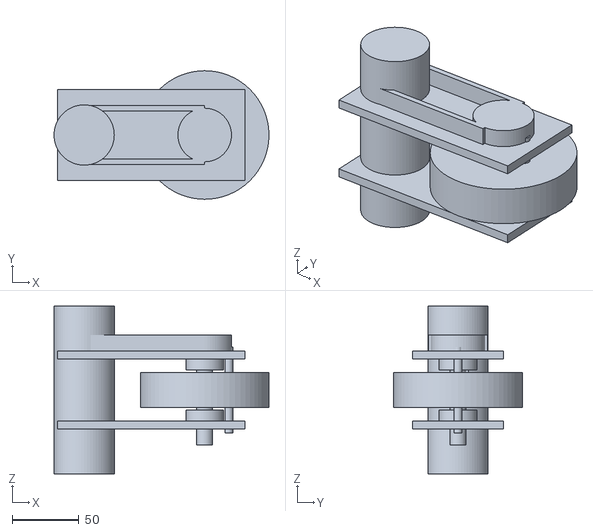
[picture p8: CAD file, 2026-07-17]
hardware/stage22_drivetrain_interface/outputs/stage22_drivetrain_interface_assembly_envelope.stl
160.5 x 96.0 x 125.2

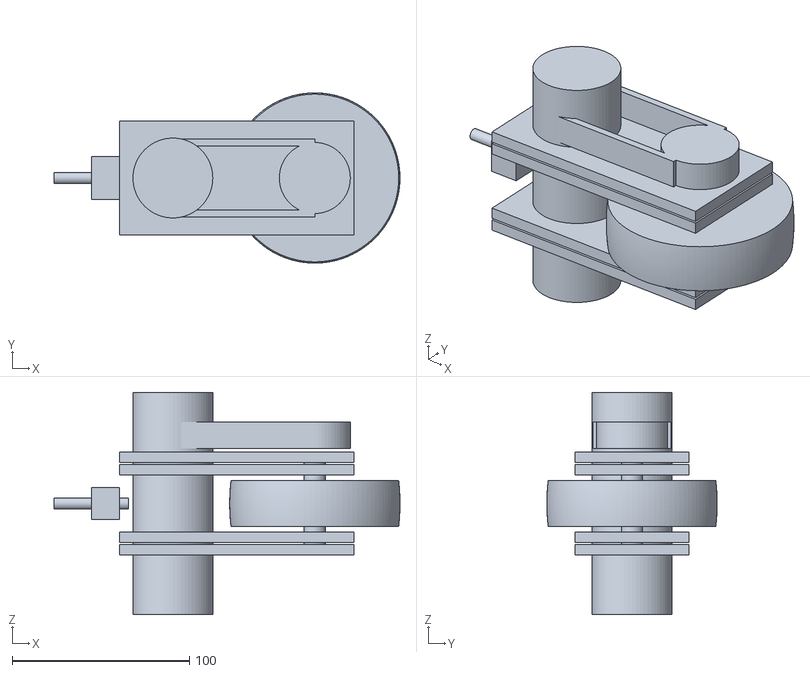
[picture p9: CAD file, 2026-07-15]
hardware/stage21_wheel_preload_adjuster/outputs/stage21_wheel_preload_assembly_envelope.stl
195.0 x 96.0 x 125.2

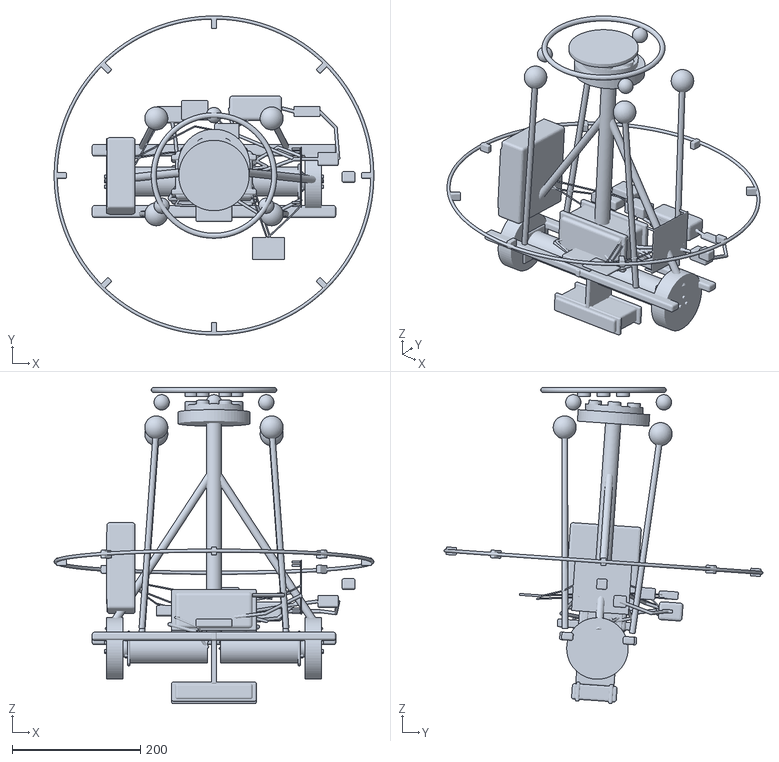
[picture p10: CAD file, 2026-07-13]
blender/exports/BB8_internal_mechanism_mm.stl
499.0 x 497.8 x 493.3

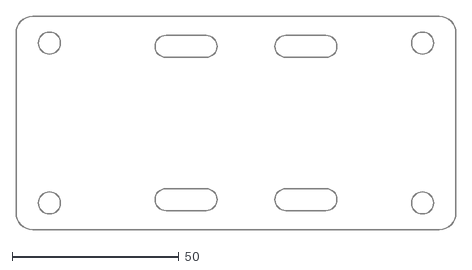
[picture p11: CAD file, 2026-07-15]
hardware/stage21_wheel_preload_adjuster/outputs/stage21_fixed_slider_plate.dxf
132.0 x 64.0

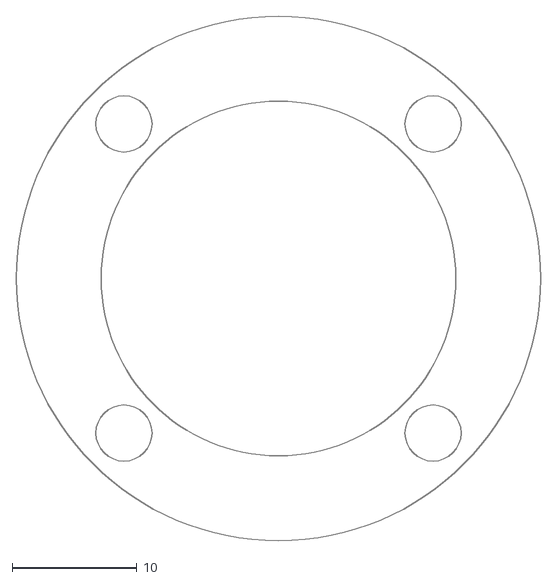
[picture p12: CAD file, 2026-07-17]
public/downloads/stage22_bearing_retainer.dxf
42.0 x 42.0

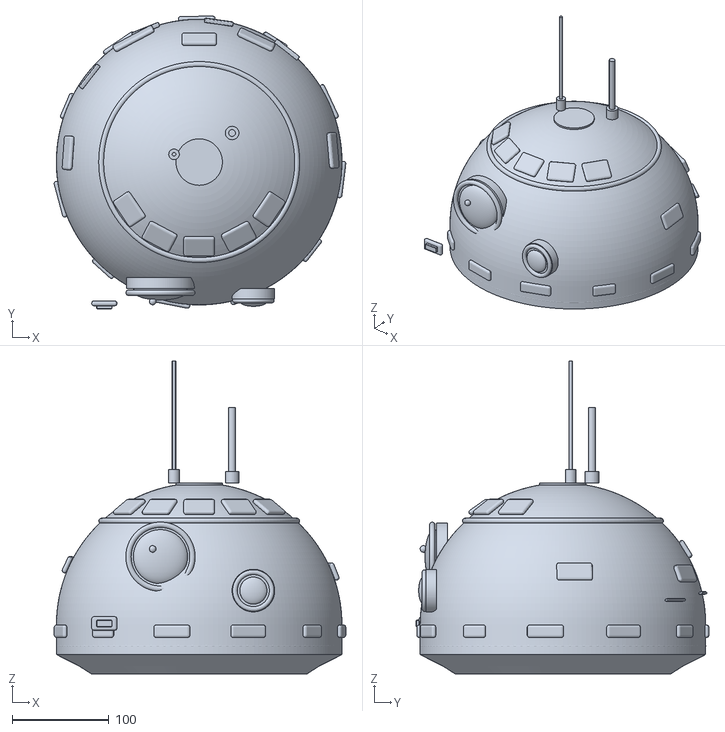
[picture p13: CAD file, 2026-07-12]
blender/exports/BB8_head_visual_reference_mm.stl
301.3 x 302.7 x 323.0

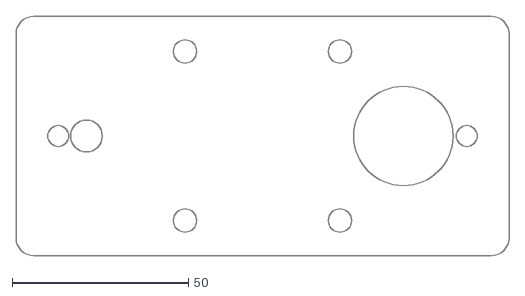
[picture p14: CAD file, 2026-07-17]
public/downloads/stage22_rail_interface_bracket.dxf
140.0 x 68.0

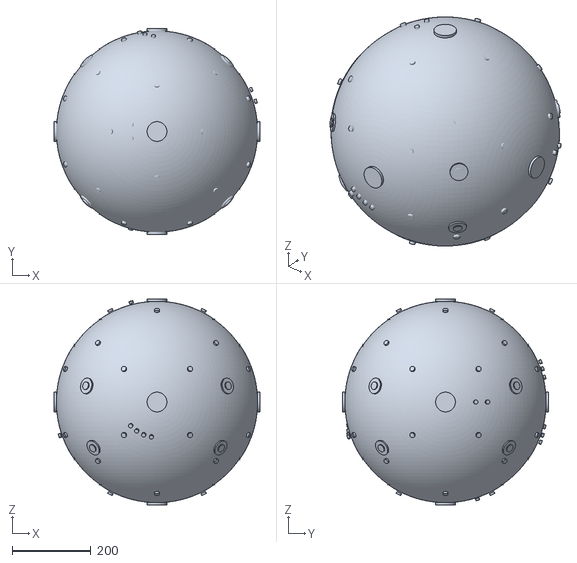
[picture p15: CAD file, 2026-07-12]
public/model/BB8_body_visual_reference_mm.stl
522.0 x 522.0 x 522.0

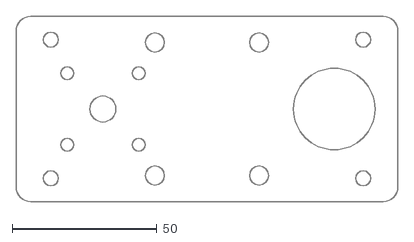
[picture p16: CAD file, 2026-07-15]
hardware/stage21_wheel_preload_adjuster/outputs/stage21_moving_side_plate.dxf
132.0 x 64.0

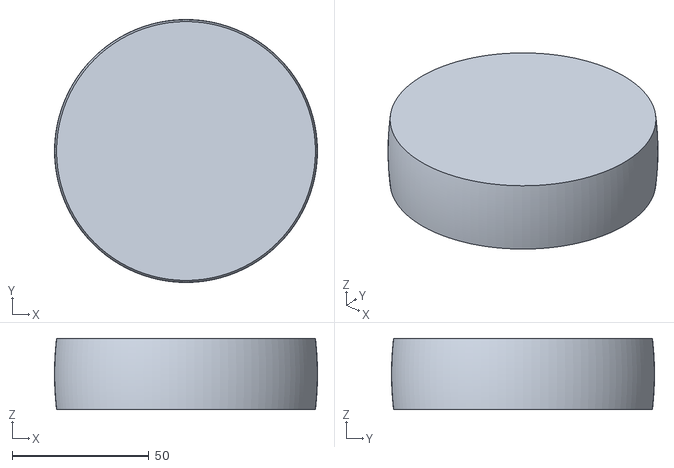
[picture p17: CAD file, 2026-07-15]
hardware/stage21_wheel_preload_adjuster/outputs/stage21_crowned_wheel_envelope.stl
96.0 x 96.0 x 26.0

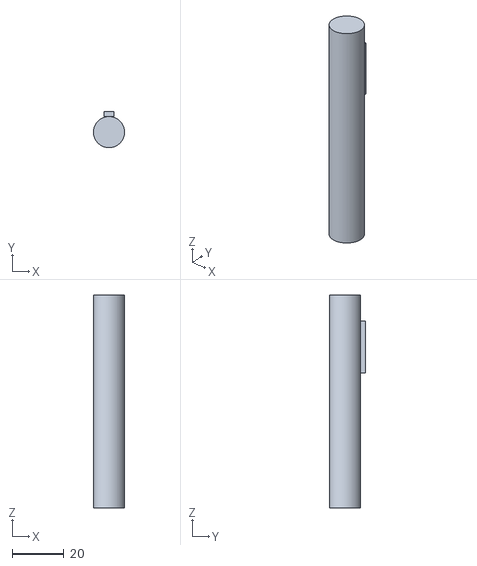
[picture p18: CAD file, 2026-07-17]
hardware/stage22_drivetrain_interface/outputs/stage22_keyed_shaft_envelope.stl
12.0 x 14.0 x 82.0

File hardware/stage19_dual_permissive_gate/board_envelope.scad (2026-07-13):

// Stage 19 pre-CAD mechanical envelope only.
// No copper, footprint, creepage, DRC or fabrication release is implied.

$fn = 48;

board_x = 50;
board_y = 35;
board_z = 1.6;
hole_d = 3.2;
holes = [[3, 3], [47, 3], [3, 32], [47, 32]];

module rounded_board() {
  difference() {
    linear_extrude(board_z)
      offset(r = 1.5)
        offset(delta = -1.5)
          square([board_x, board_y]);
    for (p = holes)
      translate([p[0], p[1], -0.1]) cylinder(d = hole_d, h = board_z + 0.2);
  }
}

module block(x, y, sx, sy, sz, label_kind = 0) {
  translate([x - sx / 2, y - sy / 2, board_z]) cube([sx, sy, sz]);
}

color([0.03, 0.28, 0.16]) rounded_board();

// JST XH top-entry connector envelopes; 9.8 mm mounting height above PCB.
color([0.92, 0.92, 0.82]) {
  block(8, 7, 7.4, 5.75, 9.8);   // J1 B2B-XH-A
  block(25, 7, 17.4, 5.75, 9.8); // J2 B6B-XH-A
  block(39, 28, 14.9, 5.75, 9.8); // J3 B5B-XH-A
  block(8, 28, 7.4, 5.75, 9.8);  // J4 B2B-XH-A
  block(18, 28, 7.4, 5.75, 9.8); // J5 B2B-XH-A
}

// Optocoupler and logic-package placement envelopes.
color([0.12, 0.12, 0.14]) {
  block(9, 17, 7.62, 4.6, 4.0); // U1 VO617A-4
  block(9, 22, 7.62, 4.6, 4.0); // U2 VO617A-4
  block(25, 17, 3.2, 3.2, 1.2); // U3 VSSOP-8
  block(32, 17, 3.2, 3.2, 1.2); // U4 VSSOP-8
  block(39, 17, 3.2, 3.2, 1.2); // U5 VSSOP-8
}

// Two 0.5 W input resistors and test-point corridor.
color([0.72, 0.42, 0.12]) {
  block(17, 16, 6.5, 2.5, 2.5);
  block(17, 21, 6.5, 2.5, 2.5);
}
color([0.8, 0.65, 0.1]) {
  for (x = [22, 26.5, 31, 35.5, 40, 44.5]) block(x, 23, 1.5, 1.5, 2.0);
}

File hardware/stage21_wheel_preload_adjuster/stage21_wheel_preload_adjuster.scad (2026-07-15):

// BB-8 Stage 21 tangent-axis wheel-preload cassette.
// REFERENCE CAD ONLY — NOT A FABRICATION RELEASE.
// Hole fits, material, fastener preload, belt rating and physical contact remain HOLD.

$fn = 72;

part = is_undef(part) ? "assembly" : part;
travel = is_undef(travel) ? 3 : travel; // 0..12 mm from inner stop; 3 mm is nominal contact.
show_shell = is_undef(show_shell) ? false : show_shell;

shell_r = 254;
wheel_r = 48;
wheel_half_width = 13;
crown_drop = 0.75;
plate_l = 132;
plate_w = 64;
plate_t = 6;
wheel_x = 110;
motor_x = 30;
axis_spacing = wheel_x - motor_x;
moving_plate_z = 19;
fixed_plate_z = 26;
slot_w = 6.6;
slot_l = 18.6;
nominal_travel = 3;
delta = travel - nominal_travel;
pulley_pitch_r = 24 * 5 / (2 * PI);
pulley_visual_r = 20;
pulley_w = 15;
pulley_z = fixed_plate_z + plate_t / 2 + pulley_w / 2 + 2;
neutral_center_r = 206;
base_origin_r = neutral_center_r - wheel_x;
nx = 155 / 206;
nz = -sqrt(1 - nx * nx);

module rounded_rect_2d(size=[20, 20], radius=3) {
    offset(r=radius) offset(delta=-radius) square(size, center=true);
}

module slot_2d(length=slot_l, width=slot_w) {
    hull() {
        translate([-(length-width)/2, 0]) circle(d=width);
        translate([(length-width)/2, 0]) circle(d=width);
    }
}

module fixed_plate_2d() {
    difference() {
        translate([plate_l/2, 0]) rounded_rect_2d([plate_l, plate_w], 5);
        // Slot centre is 3 mm outward of nominal so travel spans -3..+9 mm.
        for (x=[48, 84], y=[-23, 23])
            translate([x + 3, y]) slot_2d();
        for (x=[10, 122], y=[-24, 24])
            translate([x, y]) circle(d=6.6);
    }
}

module moving_plate_2d() {
    difference() {
        translate([plate_l/2, 0]) rounded_rect_2d([plate_l, plate_w], 5);
        translate([wheel_x, 0]) circle(d=28.2); // 6001-2RS envelope; fit not released.
        translate([motor_x, 0]) circle(d=9.0);
        for (a=[45, 135, 225, 315])
            translate([motor_x + 17.5*cos(a), 17.5*sin(a)]) circle(d=4.5);
        for (x=[48, 84], y=[-23, 23])
            translate([x, y]) circle(d=6.6);
        for (x=[12, 120], y=[-24, 24])
            translate([x, y]) circle(d=5.2);
    }
}

module fixed_plate() {
    linear_extrude(height=plate_t, center=true) fixed_plate_2d();
}

module moving_plate() {
    linear_extrude(height=plate_t, center=true) moving_plate_2d();
}

module crowned_wheel() {
    points = concat(
        [[0, -wheel_half_width]],
        [for (i=[0:24])
            let(s=-wheel_half_width + 2*wheel_half_width*i/24,
                r=wheel_r - crown_drop*pow(s/wheel_half_width, 2))
            [r, s]],
        [[0, wheel_half_width]]
    );
    rotate_extrude(convexity=10) polygon(points);
}

module pulley(bore=8) {
    difference() {
        cylinder(r=pulley_visual_r, h=pulley_w, center=true);
        cylinder(d=bore + 0.4, h=pulley_w + 2, center=true);
    }
}

module belt_envelope() {
    linear_extrude(height=pulley_w, center=true)
        difference() {
            hull() {
                translate([motor_x, 0]) circle(r=pulley_visual_r + 2);
                translate([wheel_x, 0]) circle(r=pulley_visual_r + 2);
            }
            hull() {
                translate([motor_x, 0]) circle(r=pulley_visual_r - 2);
                translate([wheel_x, 0]) circle(r=pulley_visual_r - 2);
            }
        }
}

module motor_envelope() {
    cylinder(d=45, h=125.2, center=true);
}

module wheel_shaft() {
    cylinder(d=12, h=58, center=true);
}

module bearing() {
    difference() {
        cylinder(d=28, h=8, center=true);
        cylinder(d=12, h=10, center=true);
    }
}

module jackscrew_block() {
    difference() {
        translate([-8, 0, 0]) cube([16, 24, 18], center=true);
        rotate([0, 90, 0]) cylinder(d=5.2, h=20, center=true);
    }
}

module jackscrew() {
    rotate([0, 90, 0]) cylinder(d=6, h=42, center=true);
}

module hard_stop_pair() {
    for (y=[-27, 27]) {
        translate([-1, y, 0]) cube([6, 8, 18], center=true);
        translate([plate_l+1, y, 0]) cube([6, 8, 18], center=true);
    }
}

module clamp_bolts() {
    for (x=[48, 84], y=[-23, 23])
        translate([x + delta, y, 0]) cylinder(d=6, h=64, center=true);
}

module cassette() {
    color("silver")
        for (z=[-fixed_plate_z, fixed_plate_z])
            translate([0, 0, z]) fixed_plate();
    color([0.95, 0.32, 0.07])
        for (z=[-moving_plate_z, moving_plate_z])
            translate([delta, 0, z]) moving_plate();
    color([0.08, 0.08, 0.08])
        translate([wheel_x + delta, 0, 0]) crowned_wheel();
    color([0.45, 0.47, 0.45])
        translate([motor_x + delta, 0, 0]) motor_envelope();
    color([0.75, 0.75, 0.75])
        translate([wheel_x + delta, 0, 0]) wheel_shaft();
    color([0.25, 0.25, 0.28])
        for (z=[-moving_plate_z, moving_plate_z])
            translate([wheel_x + delta, 0, z]) bearing();
    color([0.95, 0.32, 0.07]) {
        translate([motor_x + delta, 0, pulley_z]) pulley(8);
        translate([wheel_x + delta, 0, pulley_z]) pulley(12);
    }
    color([0.08, 0.08, 0.08])
        translate([delta, 0, pulley_z]) belt_envelope();
    color([0.25, 0.25, 0.25]) {
        clamp_bolts();
        translate([-16 + travel/2, 0, 0]) jackscrew();
    }
    color([0.95, 0.32, 0.07]) jackscrew_block();
    color([0.25, 0.25, 0.25]) hard_stop_pair();
}

module right_local_to_global() {
    multmatrix([
        [nx, 0, -nz, base_origin_r*nx],
        [0, 1, 0, 0],
        [nz, 0, nx, base_origin_r*nz],
        [0, 0, 0, 1]
    ]) children();
}

module left_local_to_global() {
    multmatrix([
        [-nx, 0, -nz, -base_origin_r*nx],
        [0, 1, 0, 0],
        [nz, 0, -nx, base_origin_r*nz],
        [0, 0, 0, 1]
    ]) children();
}

module global_pair() {
    right_local_to_global() cassette();
    left_local_to_global() cassette();
    if (show_shell)
        color([0.82, 0.86, 0.90, 0.16])
            difference() {
                sphere(r=shell_r + 1);
                sphere(r=shell_r - 1);
                translate([0, -320, 0]) cube([640, 640, 640], center=true);
            }
}

if (part == "fixed_plate") fixed_plate();
else if (part == "moving_plate") moving_plate();
else if (part == "fixed_plate_2d") fixed_plate_2d();
else if (part == "moving_plate_2d") moving_plate_2d();
else if (part == "jackscrew_block") jackscrew_block();
else if (part == "crowned_wheel") crowned_wheel();
else if (part == "global_pair") global_pair();
else cassette();

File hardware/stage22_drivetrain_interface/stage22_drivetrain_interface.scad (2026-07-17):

// BB-8 Stage 22 catalog-belt, bearing, keyed-shaft and rail-interface reference.
// REFERENCE CAD ONLY — NOT A FABRICATION RELEASE.
// Fits, GD&T, materials, supplier rating/tension and physical proof remain HOLD.

$fn = 72;
part = is_undef(part) ? "assembly" : part;

plate_l = 140;
plate_w = 68;
plate_t = 6;
wheel_x = 110;
motor_x = 20;
wheel_r = 48;
wheel_w = 26;
shaft_d = 12;
bearing_od = 28;
bearing_w = 8;
pulley_r = 20;
pulley_w = 15;
pulley_z = 33.5;

module rounded_rect_2d(size=[20, 20], radius=3) {
    offset(r=radius) offset(delta=-radius) square(size, center=true);
}

module rail_bracket_2d() {
    difference() {
        translate([plate_l/2, 0]) rounded_rect_2d([plate_l, plate_w], 5);
        for (x=[48, 92], y=[-24, 24])
            translate([x, y]) circle(d=6.6);
        for (x=[12, 128])
            translate([x, 0]) circle(d=6.0);
        translate([wheel_x, 0]) circle(d=28.2);
        translate([motor_x, 0]) circle(d=9.0);
    }
}

module rail_bracket() {
    linear_extrude(height=plate_t, center=true) rail_bracket_2d();
}

module bearing_retainer_2d() {
    difference() {
        circle(d=42);
        circle(d=28.4);
        for (a=[45, 135, 225, 315])
            translate([17.5*cos(a), 17.5*sin(a)]) circle(d=4.5);
    }
}

module bearing_retainer() {
    linear_extrude(height=3, center=true) bearing_retainer_2d();
}

module bearing() {
    difference() {
        cylinder(d=bearing_od, h=bearing_w, center=true);
        cylinder(d=shaft_d, h=bearing_w+2, center=true);
    }
}

module keyed_shaft_envelope() {
    union() {
        cylinder(d=shaft_d, h=82, center=true);
        translate([0, shaft_d/2+1, 21]) cube([4, 2, 20], center=true);
    }
}

module pulley(bore=shaft_d) {
    difference() {
        cylinder(r=pulley_r, h=pulley_w, center=true);
        cylinder(d=bore+0.4, h=pulley_w+2, center=true);
    }
}

module belt_envelope() {
    linear_extrude(height=pulley_w, center=true)
        difference() {
            hull() {
                translate([motor_x, 0]) circle(r=pulley_r+2);
                translate([wheel_x, 0]) circle(r=pulley_r+2);
            }
            hull() {
                translate([motor_x, 0]) circle(r=pulley_r-2);
                translate([wheel_x, 0]) circle(r=pulley_r-2);
            }
        }
}

module assembly() {
    color("silver")
        for (z=[-26, 26])
            translate([0, 0, z]) rail_bracket();
    color([0.08, 0.08, 0.08])
        translate([wheel_x, 0, 0]) cylinder(r=wheel_r, h=wheel_w, center=true);
    color([0.48, 0.50, 0.47])
        translate([motor_x, 0, 0]) cylinder(d=45, h=125.2, center=true);
    color([0.8, 0.8, 0.8])
        translate([wheel_x, 0, 0]) keyed_shaft_envelope();
    color([0.22, 0.22, 0.24])
        for (z=[-19, 19])
            translate([wheel_x, 0, z]) bearing();
    color([0.95, 0.32, 0.07]) {
        translate([motor_x, 0, pulley_z]) pulley(8);
        translate([wheel_x, 0, pulley_z]) pulley(12);
    }
    color([0.08, 0.08, 0.08])
        translate([0, 0, pulley_z]) belt_envelope();
    color([0.15, 0.38, 0.48])
        for (x=[12, 128])
            translate([x, 0, 0]) cylinder(d=6, h=64, center=true);
}

if (part == "rail_bracket") rail_bracket();
else if (part == "rail_bracket_2d") rail_bracket_2d();
else if (part == "bearing_retainer") bearing_retainer();
else if (part == "bearing_retainer_2d") bearing_retainer_2d();
else if (part == "keyed_shaft") keyed_shaft_envelope();
else assembly();

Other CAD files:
blender/checkpoints/BB8_stage01_before_internal_export_fix.blend
blender/checkpoints/BB8_stage02_panel_detail_internal_preserved.blend
blender/checkpoints/BB8_stage03_buildable_internal_assembly.blend
blender/checkpoints/BB8_stage04_IG42_contact_geometry.blend
blender/checkpoints/BB8_stage05_verified_IG42_mount.blend
blender/checkpoints/BB8_stage06_serviceable_shell_harness.blend
blender/checkpoints/BB8_stage07_magnetic_head_follower.blend
blender/checkpoints/BB8_stage08_unsaved_gui_20260712_183729.blend
blender/checkpoints/BB8_stage13_power_safety_hardware.blend
blender/checkpoints/BB8_stage13_power_safety_hardware_v2.blend
blender/checkpoints/BB8_stage13_power_safety_hardware_v3.blend
blender/checkpoints/BB8_stage14_mass_cg_ballast.blend
blender/checkpoints/BB8_stage15_drive_power_estop.blend
blender/output/BB8_1to1_screen_referenced.blend
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

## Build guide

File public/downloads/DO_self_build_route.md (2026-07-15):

# D-O 自组采购与调试路线

## 结论先行

当前已经具备一条可重复审计的 **D-O 控制系统路线**，并找到六条外部模型候选，但仍没有一个完整、可公开再分发且经过真机验证的机械 + 控制 + 电气整机包。能立即做的是：固定 v3.4.3 源码、准备控制台架、逐项验证接收机、IMU、声音和安全联锁。不能直接做的是：把免费静态模型、未完成可动模型或付费私用开发版混成一套未经验证的整机。

机械路线现在有三类：Mr Baddeley Patreon 付费 V2；Thingiverse Denton V1 免费但头部/STEP 未完成且衍生授权来源要复核；Cults JRIZZ 付费 Private-use 开发版，页面列出 Fusion 360、STL 和两个 Arduino 草图。购买属于外部付费动作，本项目不代购、不抓取、不绕过权限。两个 Printables 模型与 Gambody 关节模型只作外形/静态/改装参考，不能替代驱动与平衡设计。公开的 60 mm STL 仍只是无轮调试支架。

## 当前固定基线

- 本地仓库：`third_party/D-O-Printed-Droid`
- 固定提交：`e90aacdbe26a62fd4f0229d5504a3f2f3c409055`
- 推荐草图：`D-O_ibus_v3.4/D_O_printed_droid_rc_ibus_v3.4.3.ino`
- 控制器：Arduino Mega 2560
- 本地编译：Flash 43,198 / 253,952 B（17%），RAM 1,516 / 8,192 B（18%）
- 官方控制板页 12 个附件：本机已下载并哈希核验，保存在 Git 忽略目录；不在公开网站镜像
- AIO32 v2.1：实验性备选，22 个源码文件；ESP32 core 3.3.7 实编译通过（Flash 41%、RAM 15%），但无包级 LICENSE、无已找到的 KiCad/Gerber，且手册遗漏 SensorLib 依赖，不属于当前装机基线
- 机器可读采购清单：`engineering/do_self_build_bom.csv`

Mega 与 AIO32 编译通过只证明对应依赖和源码能生成固件，不证明真实电机、电池、机械结构或平衡控制已经安全。

## 先冻结的七个采购门

### G1：取得合法机械包

先明确路线，再通过创作者授权渠道取得所需版本：

- **Denton V1 免费 WIP：** 先下载后逐文件盘点，确认头部是否仍缺失、STEP 是否真的不存在、3D PDF/STL 是否覆盖全部子总成，并复核 Baddeley 派生几何的许可来源；在完成前保持 `HOLD_INCOMPLETE_HEAD_ARCHIVE_AND_PROVENANCE_REVIEW`。
- **JRIZZ / Cults 付费开发版：** 只有在用户明确确认购买和接受 `CULTS - Private Use` 后才能获取；收到后核对 F3Z、两个 Arduino 草图、STL 清单和实际硬件修订，保持 `PAID_PRIVATE_USE_NOT_ACQUIRED_OR_VERIFIED` 直到验包完成。
- **Mr Baddeley Patreon V2：** 通过创作者渠道购买并记录版本与个人使用条款。
- **Printables / Gambody：** 仅用于静态外形、分色、关节或改装空间参考，不作为自平衡可动底盘的默认机械基线。

无论选择哪条路线，都要确认文件中包含哪些 STL、Fusion/STEP、BOM、打印方向和装配修订。付费访问不等于开源，也不自动授予再分发权。

**通过条件：** 文件版本、个人使用条款和完整清单已记录；缺件不再靠视频截图猜测。

### G2：解决驱动板冲突

仓库根 README 写的是 **一块 Cytron MDD10A 双路驱动**，v3.4 README 的硬件表写的是 **两块 MD10C**。两种方案都可能匹配草图的两组 PWM/DIR 输出，但接线、额定电流、散热和控制板布局不同。

**通过条件：** 根据实际控制板/接线图和电机峰值电流锁定一种架构；在此之前不购买驱动板。

### G3：测出驱动负载

公开控制仓库没有锁定驱动电机型号、减速比、轮径、整机质量、质心和真实堵转电流。README 中的电流数字只能作为来源记录，不能作为保险丝和驱动板选型依据。

**通过条件：** 实测空载电流、堵转/限流电流、轮端转矩、速度和热升；连续工况保留工程裕量。

### G4：测出四个舵机负载

README 同时写“4 个 standard servo”和“SG90 or similar”，这不是可直接采购的机械规格。主杆、头部俯仰/偏航/滚转的扭矩和行程必须从机械包量取。

**通过条件：** 每轴的静态/动态峰值扭矩、速度、角度、安装空间和供电电流已记录；舵机至少保留 2 倍实测扭矩裕量。

### G5：完成电源与安全设计

来源建议两块 2S LiPo 串联，形成 4S：16.8 V 满电、14.8 V 标称、12.0 V 空电。Mega、舵机、DFPlayer 和接收机不能直接共享未经设计的 4S 电源路径。

**通过条件：** 主保险、分支保护、硬件断电、逻辑稳压、舵机 BEC、导线截面积、连接器和散热均依据实测峰值电流确定。四个舵机不得由 Mega 5 V 引脚直接供电。

### G6：解决 Serial0 与 D0/D1 舵机复用

v3.4.3 源码把主杆舵机和头部舵机 1 固定到 D0、D1，同时执行 `Serial.begin(9600)` 并通过 Serial0 提供启动菜单、参数配置和测试命令。Mega 2560 官方引脚表把 D0/D1 定义为 RX0/TX0，因此这是同一对物理引脚的功能争用，不是可以忽略的文档差异。

项目现在提供 `tools/build_do_safe_pin_variant.py`：它只接受固定提交 `e90aacd...` 和原始源码 SHA-256 `6cb3ce0d...`，不公开修改后的第三方源码或二进制，而是在本机把四路舵机统一改到 D22/D23/D24/D25，释放 D0/RX0 与 D1/TX0 给 Serial0。该变体已用 Mega 2560 重新编译，Flash 43,198 B（17%）、RAM 1,516 B（18%），修改后源码 SHA-256 为 `f858c485...`。

**当前状态：** `SOFTWARE_REMAP_READY_HOLD_PHYSICAL_CONTINUITY`。软件级引脚冲突已在这个固定变体中消除，但示波器/逻辑分析仪、USB 上传、复位、9600 baud 菜单收发、四路舵机脉宽和失效保护均未实测；在这些证据完成前不接舵机电源。

### G7：冻结固件版本与接线图

Printed Droid 控制板页面内嵌的 **v2.1** 接线表把四个舵机列为 D2/D3/D4/D5；当前固定的 **v3.4.3** 源码和 GitHub README 则使用 D0/D1/D5/D6。页面的 `D-O_ibus_v3.4.zip` 也不是当前版本，其源码头为 v3.4.0。混用这些入口会把舵机接错，并掩盖 G6 的 Serial0 争用。

**当前状态：** 已生成 [D22–D25 线束合同](../engineering/do_safe_pin_variant_wiring.csv) 和 [编译证据](../engineering/do_safe_pin_variant_compile.json)，并绑定原始提交、原始/修改后 SHA-256 和四路常量；状态前进为 `VARIANT_WIRING_GENERATED_HOLD_CONTINUITY`。上电前仍必须逐网导通确认，官网 v3.4 ZIP 只作历史参考，转换输入只允许 GitHub 固定的 v3.4.3。

## v3.4.3 原始接线与安全变体

| Mega 引脚 | 功能 | 说明 |
|---|---|---|
| D0 / RX0 | 主杆舵机 | 与 Serial0 RX 复用；当前 HOLD，不接入首轮台架 |
| D1 / TX0 | 头部舵机 1 | 与 Serial0 TX 复用；当前 HOLD，不接入首轮台架 |
| D3 / D4 | PWM 驱动输入 | 仅 Mode 0 |
| D5 / D6 | 头部舵机 2 / 3 | 偏航 / 滚转 |
| D7 / D8 | DFPlayer RX / TX | Mega 直接控制声音 |
| D10 / D11 | 电机 2 PWM / DIR | 驱动板通道 2 |
| D12 / D13 | 电机 1 PWM / DIR | 驱动板通道 1 |
| D14–D17 | 四路声音开关 | 仅 Mode 0 |
| D19 | iBus RX | Mode 1；接收机与 Mega 共地 |
| D20 / D21 | SDA / SCL | IMU，400 kHz I2C |
| A15 | 电池采样 | 10 kΩ + 3.3 kΩ 分压 |

SBUS 也可进入 D19，但 Mega 不能自行反相，必须有外部硬件反相器。对新制作优先用 Mode 1 iBus，减少 PWM 线束；接收机必须真实提供 10 个通道，FS-iA6B 的 6 通道不足以覆盖默认完整映射。

以上表格记录的是固定上游 v3.4.3 的原始现状，不表示 D0/D1 方案已被接受。当前可编译的安全变体把主杆/头1/头2/头3依次接到 **D22/D23/D24/D25**；完整字段见 `do_safe_pin_variant_wiring.csv`。不能使用官网内嵌的 v2.1 D2–D5 表，也不能把未转换的 v3.4.3 接线和安全变体混接。官方 Mega 2560 串口映射见 https://docs.arduino.cc/language-reference/en/functions/communication/serial/ 。

## 分阶段调试路线

### D01 — 建立合法文件台账

**动作：** 记录机械包版本、许可证/个人使用条款、PDF、源码提交和每个文件哈希；把官网 12 个公开附件与 Patreon 付费文件分开登记。

**验收：** 所有付费与公开资源边界清楚；网站下载区没有再分发未授权 STL/Fusion。

### D02 — 冻结电气架构

**动作：** 依据实际控制板、接线图和电机峰值电流，解决 MDD10A 与 MD10C 冲突；画出电池、保险、断电开关、驱动、逻辑稳压和舵机 BEC 的单线图。

**验收：** 每条电源支路有电压、连续/峰值电流、线径、连接器和保护值；4S 满电 16.8 V 不会进入超额定电路。

### D03 — 无电机械干装

**动作：** 按授权机械包干装轮、轴承、主杆和头部机构，检查同轴度、间隙、重心和线束运动包络。

**验收：** 手动全行程无卡滞；紧固件可维护；线束不进入轮、齿轮和舵机臂扫掠区。

### D04 — 连续性与极性检查

**动作：** 在未接电池时逐网测量，核对公共地、正负极、分压器、保险和硬件断电。

**验收：** 无短路；所有连接器有标签和防反插方案；断电开关可从安全位置触达。

### D05 — USB 单板启动

**动作：** 只接 Mega USB，不接电机、电池和任何舵机；运行 `python3 tools/build_do_safe_pin_variant.py`，核对输出的原始/修改后 SHA-256，再烧录本机生成的 D22–D25 变体，不使用官网仍为 v3.4.0 的泛名 ZIP，也不烧录未改配的 D0/D1 原版。

**验收：** 9600 baud 串口稳定显示版本；无两秒复位循环；上传的源码路径、提交、SHA-256、编译报告和版本化线束图已归档。

### D06 — IMU 单项验证

**动作：** 接入 IMU，运行菜单 `i` 检查轴向，再运行 `c` 或菜单 8 校准。

**验收：** WHO_AM_I 正确；前后倾与平衡角方向一致；静止零点稳定；I2C 400 kHz 连续运行无错误。

### D07 — 遥控链路验证

**动作：** 先打开遥控器，再启动控制器；菜单 `t` 查看所有通道，菜单 `p` 固定映射。

**验收：** `SIGNAL: OK`；CH1–CH10 逐项可识别；断开遥控后输入归中且操作员仍能硬件断电。

### D08 — 声音链路验证

**动作：** FAT16/FAT32 卡建立 `/mp3/0001.mp3` 至 `/mp3/0032.mp3` 的合法音频集合，接入 DFPlayer 与扬声器。

**验收：** 启动、警告和失联声音地址正确；最大所需音量无明显削波、复位或电源噪声。

### D09 — 舵机空载验证

**动作：** 舵机使用独立 BEC，只接一轴开始，逐步扩展到四轴；先限制角度与速度。四路信号只按安全变体的 D22–D25 线束合同连接，并先通过 G7 的版本化导通表；D0/D1 不再接舵机。

**验收：** 四轴方向、零位、软限位正确；同步动作时舵机电源不跌落，Mega 不复位；USB 上传和 9600 baud 配置菜单仍可靠，且逻辑分析仪记录不存在 Serial0/舵机脉冲争用。

### D10 — 电机架空验证

**动作：** 将底盘固定在轮子离地的支架上，限流电源起步；用菜单 `m` 单独检查左右电机、方向交换和反向配置。

**验收：** 硬件断电立即让两电机失能；方向标记一致；空载电流和驱动温升已记录；手不进入轮子包络。

### D11 — A15 电池测量校准

**动作：** 接入 10 kΩ + 3.3 kΩ 分压，先用实验电源模拟电池电压，再启用监测。

**验收：** 满电、中点和低压三点与校准万用表误差在项目设定范围内；未接分压器时不启用电池监测。

### D12 — 低压与故障门

**动作：** 模拟临界电压、IMU 断线、遥控失联、超过 45° 倾倒和看门狗恢复。

**验收：** 行为与风险评估一致；每个故障的电机输出、声音和恢复条件均有记录。注意：源码设计中遥控失联仍可能继续平衡，不能把它当作完全断电。

### D13 — 系留首个平衡闭环

**动作：** 拆下头部并降低质心，使用两侧软系留和随手可达的硬件断电；从低输出限制和保守 PID 开始。

**验收：** 连续 30 秒不过流、不撞限位、不出现高频振荡；任何异常可在不靠近轮子的情况下断电。

### D14 — 装头与主杆耦合

**动作：** 逐项增加主杆和头部自由度，重新测量质心与平衡参数。

**验收：** 全姿态无机械干涉；舵机峰值电流、温升和回差记录完整；平衡控制不被头部动作击穿。

### D15 — 低速地面试验

**动作：** 在空旷区域，以低速度、低加速度完成直行、停止、转向和失联演练。

**验收：** 可预测停止；无电池压降复位；操作者始终保持安全距离并能远程/硬件切断。

### D16 — 热与耐久门

**动作：** 按真实任务循环运行，记录电池、电机、驱动器、稳压器、舵机和连接器温度。

**验收：** 在最高环境温度和最低电量下仍低于各器件额定限制；没有松动、磨线或连接器变色。

## 现在可买与暂缓购买

**可先买、风险较低：** Mega 2560、已确认逻辑电压的 MPU6050 模块、10 通道 iBus 接收机/遥控器、DFPlayer、microSD、8 Ω 小功率扬声器、精密 10 kΩ 与 3.3 kΩ 电阻、1 kΩ 电阻、合适耐压的 100 µF 电容、台架用线材和保险座。

**必须暂缓：** 驱动板、驱动电机/减速箱、四个最终舵机、最终 BEC/稳压器、LiPo 容量与 C 值、批量轴承/紧固件，以及任何声称包含完整 D-O 的非授权机械包。D22–D25 舵机线束也不得制造冻结，直到逐网导通、USB/Serial0 和四路脉宽实测通过。

## 复核命令

```bash
python3 tools/audit_do_resources.py
python3 tools/audit_do_mantis_videos.py
tools/compile_do_firmware.sh
python3 tools/build_do_safe_pin_variant.py
```

第一个命令核对仓库提交、许可证、PDF 哈希和机械文件缺口；第二个命令只读取 Mantis 播放列表元数据与描述链接，不下载视频；第三个命令重编译原始 v3.4.3；最后一个命令对固定原始 SHA-256 做 D22–D25 转换、重新编译并刷新线束/证据文件。

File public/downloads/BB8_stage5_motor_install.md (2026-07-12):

# BB-8 阶段 5：IG42E 电机安装与拆装

> 这是采购前的可装配设计冻结，不是最终加工图。电机 M4 孔位有厂家图纸依据；键毂 3×M5 节圆仍需专用图纸或实物复测。

## 已冻结接口

| 接口 | 当前设计值 | 证据/状态 |
|---|---:|---|
| 电机最大包络 | Ø45 × 125.2 mm | Cytron 关联的 Sha Yang Ye IG-42GM 图纸 |
| 输出轴 | Ø8 × 20 mm | 厂家图纸 |
| 电机安装孔 | 4×M4×6 深，PCD 35 mm | 厂家图纸 |
| 电机面板 | 4 mm 6061-T6，外形 52 × 52 mm | 本项目设计 |
| 左右轮距 | 310 mm | 为容纳两台125.2 mm电机并保留19.6 mm中央间隙 |
| 键毂 | Ø26 × 40 mm，8 mm孔，3×M5 | Cytron商品页；M5节圆待确认 |
| 驱动轮 | Ø96 × 26 mm | 本项目动力学基准 |

## 装配顺序

1. 将两块电机面板先空装到左右纵梁，使用M4低头螺钉；暂不涂螺纹锁固剂。
2. 从球体中央分别向左右插入IG42E，使输出轴朝外；确认两电机尾部中央间隙不小于15 mm。
3. 将4枚M4螺钉按对角顺序轻拧入每台电机，螺纹进入电机不得超过6 mm。
4. 把8 mm键毂套到输出轴，先安装夹紧用M4螺钉；轮毂端面与电机面之间保留不小于1 mm间隙。
5. 用3枚M5将96 mm轮连接到键毂。当前模型中的M5径向位置仅用于空间验证，实物孔位必须随采购键毂复测。
6. 手转两轮一整圈，确认不刮电机面板、纵梁、线束和球壳；再接入电源。
7. 完成架空低速测试后，才可对已确认需要防松的位置使用可拆卸中强度螺纹锁固剂。

## 拆装和工具可达性

- 每块电机面板保留55 mm工具操作包络，适配常见M4内六角工具和手指夹持。
- 中央横梁只有8 mm宽，避免侵入两台电机尾部；拆除任一侧面板后，电机可向球心方向抽出。
- 电机动力线和编码器线必须先断开再拆面板，禁止用线束拉出电机。
- 强磁头、电池和主保险丝必须先移除，防止球体意外滚动或电机误启动。

## 实物到货复测表

| 项目 | 图纸值 | 实测值 | 判定 |
|---|---:|---:|---|
| 总长（含20 mm轴） | 125.2 mm | 待测 | 待定 |
| 最大外径 | 45 mm | 待测 | 待定 |
| M4孔PCD | 35 mm | 待测 | 待定 |
| 键毂3×M5节圆 | 未确认 | 待测 | 阻塞最终轮加工 |
| 单电机质量 | 360/609 g来源冲突 | 待称重 | 阻塞最终质心复算 |

## 采购前仍需确认

- 具体供应商和采购批次；
- 键毂的完整二维图或样件；
- 电机尾部Molex/JST插头加线束的最小弯曲半径；
- 球壳真实厚度、内表面摩擦系数与驱动轮材料。

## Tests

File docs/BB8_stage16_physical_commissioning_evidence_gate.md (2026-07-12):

# BB-8 Stage 16: physical commissioning evidence gate

> Current result: `HOLD_PHYSICAL_TESTS_NOT_RUN`. Stage 16 defines nineteen mandatory physical gates and machine-checks telemetry, measurement limits, evidence files and SHA-256 hashes. All nineteen remain `NOT_RUN`, so the project does not claim that a physical BB-8 has run.

## Why this stage exists

Stages 10–15 cover closed-loop control, sensors, current protection, mass and CoM, drive power, a hard E-stop and an analytical grade envelope. They did not provide one auditable path from real instruments, video, photographs and serial logs to each acceptance decision. Simulation, firmware compilation and Blender geometry are not physical-running proof.

Stage 16 adds three linked contracts:

1. `engineering/commissioning_test_plan.json` defines nineteen tests, required metrics, limits and accepted evidence kinds.
2. `engineering/commissioning_evidence.json` is the real-hardware record for serial number, operator, date, measurements and files.
3. `tools/verify_commissioning_evidence.py` checks coverage, limits, safe relative paths, file existence and SHA-256. A PASS without real files is invalid.

## Nineteen mandatory gates

| Group | Tests | Primary acceptance line |
|---|---|---|
| Mechanical/head | M01, H01 | Mass within the current 10.628 kg envelope, CoM at least 20 mm below centre, ≥40 N pull-off through the installed 8 mm gap |
| Electrical/control | E01–E03, C01 | Dual normally-closed channels, polarity/isolation, hard EN removal, dual INA226 error ≤3%, encoder repeat error ≤1% |
| Drive/thermal | D01–D02, T01–T02 | Raised-wheel no-load run, controlled stall cutoff ≤300 ms, 20 min open and 15 min sealed thermal runs |
| Ground | G01–G04 | 5 m at 0.10 m/s, 0.8 m turn, E-stop distance ≤0.50 m from 0.30 m/s, powered 3° ramp |
| Fault/power | F01–F02, P01 | Lost command and stale IMU/encoder/current data all remove EN; regenerative bus peak ≤16.8 V |
| Service/final | S01, L01 | Twenty damage-free service cycles; only then a ten-minute integrated run inside soft barriers |

These are conservative first-run limits for the current design envelope. If the final motor driver, fuse, contactor, battery or BMS rating is lower, the lower device limit governs.

## Physical telemetry

The ESP32 now emits a timestamped fixed field set every 200 ms: enable, fault, commanded motion, battery, temperature, E-stop, remote state, IMU, encoders, tilt, yaw, wheel speeds, motor currents, power readiness, hardware trip and PWM. Convert a preserved serial-monitor log with:

This telemetry build compiles for Arduino-ESP32 3.3.10 / Generic ESP32-S3 at 370,095 program bytes (28%) and 24,676 global bytes (7%). Compilation is not board-upload or powered-test evidence.

```bash
python3 tools/parse_bb8_telemetry.py \
  --input evidence/run-001/serial.log \
  --output evidence/run-001/telemetry.csv \
  --summary evidence/run-001/telemetry_summary.json
```

The parser rejects missing fields, non-finite values and non-increasing timestamps. It does not promote telemetry to PASS; each gate still needs the required camera, instrument or measurement evidence.

## Recording and verification

1. Create one directory for each real run, such as `evidence/BB8-001/2026-07-12-G01/`.
2. Preserve untouched serial logs, video/photos and instrument exports.
3. Hash every file and add its relative path, kind and SHA-256 to the corresponding evidence record.
4. Enter measured metrics and use only `NOT_RUN`, `BLOCKED`, `PASS` or `FAIL`.
5. Run `python3 tools/verify_commissioning_evidence.py`; incomplete real hardware must remain `HOLD_PHYSICAL_TESTS_NOT_RUN`.
6. `--require-pass` can succeed only when all nineteen mandatory records have matching real files, compliant metrics, a hardware serial, operator and date.

## Anti-false-PASS regression

- The current blank real-hardware template must evaluate to HOLD.
- Changing every status to PASS without metrics and files must evaluate to `INVALID_EVIDENCE`.
- Synthetic data can exercise the evaluator only inside its test-only hidden mode; normal audits reject `SYNTHETIC_TEST_ONLY`.

## Boundary that remains

- No physical BB-8 has been assembled and connected within this project, so every gate remains `NOT_RUN`.
- There is no mechanical parking brake; G04 covers powered grade motion, never unpowered holding.
- Final driver, fuse, contactor, BMS and battery choices must be frozen against their data sheets and measured currents before powered testing.
- L01 is not a first test. It follows the other eighteen gates and requires soft barriers, a wired tether E-stop and an observer.

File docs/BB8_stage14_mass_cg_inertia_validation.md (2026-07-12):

# BB-8 Stage 14: Mass, Centre of Mass and Inertia Validation

> Result: **PASS_WITH_MASS_AND_ACCELERATION_DERATING**. With the sealed low ballast cassette, even the worst enumerated mass corner keeps the centre of mass below the sphere centre. Every assumed mass must still be replaced by a measured value.

## Model-driven results

- Nominal total mass: **8.463 kg**; input range 6.375–10.628 kg.
- Nominal CoM: x=1.9 mm, y=1.4 mm, z=-56.2 mm.
- Exhaustive corner range: z=-74.5 to -27.7 mm; worst-case offset below centre 27.7 mm.
- CoM inertias: Ixx=0.2386, Iyy=0.2703, Izz=0.1085 kg·m².
- Restoring torque at 10°: 0.81 N·m; small-angle pitch period: 1.51 s.

## Ballast and drive constraints

- Blender now contains a 120 × 70 × 24 mm sealed steel ballast cassette, nominally 1.50 kg, with a centre hanger, two retention straps and four captive M5 fasteners.
- With 0.6 N·m continuous torque, a 2× margin and the nominal mass, the acceleration ceiling is **0.703 m/s²**; the controller target is frozen at 0.70 m/s².
- The equivalent steady lean at 0.70 m/s² is 4.08°. The ±4° animation is illustrative, not a control limit.
- Reaching the old unverified 110 mm offset would need about **4.14 kg** more at z=-220 mm and would reduce acceleration headroom, so 110 mm is no longer presented as a design fact.

## Checks

- PASS — nominal_com_offset
- PASS — worst_case_com_offset
- PASS — continuous_torque_derated_acceleration

## Evidence boundary

All 17 mass groups remain `NOT_RUN`, supplier-conflicted, or design assumptions. Before fabrication approval, weigh every component and measure whole-system CoM by suspension or four-scale testing, then regenerate this report from those measurements.

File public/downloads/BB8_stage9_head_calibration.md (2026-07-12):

# BB-8 阶段 9.3：头部外观与 670 mm 高度校准

更新时间：2026-07-12（Asia/Shanghai）

## 本轮结论

主工程的无天线总高已从 673 mm 收敛为 670 mm，以匹配 StarWars.com 资料库公开的 0.67 m。身体球保持 Ø508 mm，头部最大直径保持 Ø295 mm，头部可见轮廓高度采用 197 mm。

这套拆分尺寸是“官方总高 + 社区摄影测量 + 公开画面描摹”的可审计复刻基准，不是 Lucasfilm 官方 CAD，也不能据此宣称逐毫米复制电影道具。

## 尺寸闭环

| 项目 | 当前值 | 依据等级 |
| --- | ---: | --- |
| 无天线总高 | 670 mm | StarWars.com 公开 0.67 m |
| 身体球直径 | 508 mm | 社区摄影测量 |
| 头部最大直径 | 295 mm | 社区摄影测量 |
| 头部可见轮廓高度 | 197 mm | 社区摄影测量 |
| 头部下锥高度 | 20 mm | 社区摄影测量 |
| 最大直径围带高度 | 31 mm | 社区摄影测量 |
| 头部下缘直径 | 223 mm | 社区摄影测量 |
| 头体轮廓交叠 | 35 mm | 由 670 − 508 − 197 反算 |

坐标关系为：球体顶点 `z = 254 mm`；头部轮廓下缘 `z = 219 mm`；因此头部在正交轮廓上进入球体上缘 35 mm，最终得到 `254 mm + 416 mm = 670 mm` 的无天线总高。

## 头部外观修正

- 将旧的碗状头壳改为 20 mm 下锥、31 mm 围带与椭圆半穹顶组合。
- 主摄影眼移到观察者左侧，全息投影器位于观察者右侧，并使用深色光学玻璃而不是亮蓝粗环。
- 删除四块错误的大圆形橙色头板。
- 增加 11 块下围带橙色分段、两道深色下部条带、上部细橙线、五块顶部石墨维护板和顶部服务盖。
- 增加侧面与后部最低限度的维护板和缝线，缩短两根天线并增加分级底座。
- 白色、橙色和石墨材质向电影画面中的暖白、烧橙和深灰收敛；程序化污渍只表示视觉磨损，不是色卡认证。

## 自动审计门

`blender/audit_bb8.py` 现在额外检查：

- 场景元数据为 508 / 295 / 670 mm；
- 可见几何无天线高度为 670 mm；
- 头部轮廓下缘位于 219 mm；
- 下围带橙色分段恰为 11 块；
- 顶部石墨维护板恰为 5 块；
- 已不存在旧版 `Head orange panel*` 对象；
- 三视图合成图必须晚于三张正交源图，网站副本必须逐字节一致。

## 当前可复现文件指纹

- 主工程 `blender/output/BB8_1to1_screen_referenced.blend`：`c4dd9fbd9a6f931992797ecbfa96d5a3559686047a40362821e7706e4b236ff0`
- 三视图尺寸图 `blender/output/BB8_three_view_dimension_sheet.png`：`09f9e155b7489bea25c5da63023390c6e0219f924684368010bc677294bfeac4`
- 动画 GLB `blender/exports/BB8_1to1_kinematic.glb`：`bbf5ae88e22e5c8e96b4c54cbd87a33e950e7ee7ae2f582d8b89c6aabd55586c`
- 身体 STL：`8d3d35cb1da9ffb60034ba1b340ab9e27b3dd2c028903e678f25fea635d825a4`
- 头部 STL：`5370bb18ff74e992195412c04ed4424d355482c5c7d3f7dcff62848843a61c29`
- 内部机构 STL：`4f5b67a637651efc8a223c7a63739cd1a7ba028972a56c118726261b8b7b0975`

后台重开审计为 `PASS`：292 个对象、88 个内部对象、6 个主面板、8 个角区、R1/R2/R3=3/2/1，场景元数据与几何总高均为 508/295/670 mm。

## 尚未完成的精度边界

- 头部侧后方每一条切线、板缝深度与灯罩尺寸仍需要授权扫描或已知镜头参数的正交照片校准。
- 球体六块主面板已做方向和环型差异，但细槽、切线和磨损分布仍是视觉近似。
- 当前模型可用于结构验证、全尺寸布局和个人非商业原型；不应直接当作官方制造图或可售角色模型。

## 来源

- StarWars.com Databank, *BB-8*：公开高度 0.67 m。
- StarWars.com, *Droid Dreams: How Neal Scanlan and the Star Wars: The Force Awakens Team Brought BB-8 to Life*：实体道具与运动表现背景。
- Rimstar, *BB-8 Dimensions*：508、295、197、31、20、223 mm 的摄影测量整理。

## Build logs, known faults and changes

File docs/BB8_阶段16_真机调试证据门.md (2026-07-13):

# BB-8 阶段16：真机调试证据门

> 当前结论：`HOLD_PHYSICAL_TESTS_NOT_RUN`。Stage 16 已把真机验收拆成19个强制门，并建立串口遥测解析、实物证据文件、SHA-256和测量限值的机器审计；当前19项均为 `NOT_RUN`，因此不能声明整机已经实物跑通。

## 为什么需要这一阶段

阶段10–15已经覆盖闭环控制、传感器、电流保护、质量质心、驱动电源、硬件急停和动态坡道解析，但此前没有统一的方法把真实仪表记录、视频、照片、串口日志和测量表绑定到每一个验收结论。仅凭仿真PASS、固件编译或Blender几何，不能证明真实BB-8能安全运动。

Stage 16新增三层证据合同：

1. `engineering/commissioning_test_plan.json`：19项真机测试、测量字段、上下限和允许的证据类型。
2. `engineering/commissioning_evidence.json`：只填写真实硬件序列号、操作者、日期、测量值和证据文件。
3. `tools/verify_commissioning_evidence.py`：校验测试覆盖、限值、相对路径、文件存在性和SHA-256；没有真实文件不能写成PASS。

## 19个强制验收门

| 分组 | 测试 | 关键验收线 |
|---|---|---|
| 机械/头部 | M01、H01 | 整机质量不超过当前10.628 kg包络；质心低于球心至少20 mm；实际8 mm气隙拉脱力≥40 N |
| 电气/控制 | E01–E03、C01 | 双通道常闭、极性/绝缘、SAFE_A/B与ALERT独立拉低PWM、3.3 V掉电、接触器释放、双INA226误差≤3%、编码器重复误差≤1% |
| 驱动/热 | D01–D02、T01–T02 | 架空空载、≤300 ms受控堵转切断、20 min开壳与15 min封壳热试验 |
| 地面 | G01–G04 | 5 m/0.10 m/s直行、0.8 m半径转弯、0.30 m/s急停距离≤0.50 m、3°带电坡道 |
| 故障/电源 | F01–F02、P01 | 指令丢失、IMU/编码器/电流失效均撤销EN；再生母线峰值≤16.8 V |
| 维护/综合 | S01、L01 | 20次开合无损；全部前置门通过后才能进行10 min封闭区域综合运行 |

这些限值是当前设计包络的保守首轮门槛。如果最终驱动器、电池、保险丝、接触器或电机厂家额定更低，必须采用更低限值，不能用本表放宽器件约束。

## 真机遥测格式

ESP32每200 ms输出一行带 `t_ms` 的固定键值：使能、故障、命令速度、电池、温度、急停、遥控、IMU、编码器、倾角、偏航、左右轮速、左右电流、保护状态、硬件ALERT和PWM。保存串口原始文本后运行：

该遥测版本已用 Arduino-ESP32 3.3.10 / Generic ESP32-S3重新编译：程序370095 bytes（28%），全局变量24676 bytes（7%）。这仍是编译证据，不是开发板上传或带电试验。

```bash
python3 tools/parse_bb8_telemetry.py \
  --input evidence/run-001/serial.log \
  --output evidence/run-001/telemetry.csv \
  --summary evidence/run-001/telemetry_summary.json
```

解析器拒绝缺字段、非有限数值和不递增的时间戳。它不会自动把遥测变成PASS；每个测试仍必须补充相机、仪表或测量表证据。

## 填写和审计顺序

1. 为每次真机测试建立独立目录，例如 `evidence/BB8-001/2026-07-12-G01/`。
2. 保留未经编辑的原始串口日志、视频/照片和仪表导出。
3. 对每个文件计算SHA-256，在 `commissioning_evidence.json` 对应记录中填写相对路径、类型和哈希。
4. 填写实测数值；状态只能是 `NOT_RUN`、`BLOCKED`、`PASS` 或 `FAIL`。
5. 运行 `python3 tools/verify_commissioning_evidence.py`。未完成时应得到 `HOLD_PHYSICAL_TESTS_NOT_RUN`。
6. 只有19项强制门全部有真实匹配文件、数值都满足限值、整机序列号/操作者/日期齐全时，`--require-pass` 才可能成功。

## 防止伪PASS的回归测试

- 当前空白真实模板必须得到HOLD，而不是PASS。
- 把所有状态直接改成PASS但不提供测量值和文件，必须得到 `INVALID_EVIDENCE`。
- 合成数据只能在单元测试的隐藏允许模式下验证程序分支，默认审计明确拒绝 `SYNTHETIC_TEST_ONLY`。

## 当前不可跨越的边界

- 真实BB-8硬件尚未在本项目中组装并接入，因此19项均为 `NOT_RUN`。
- 没有机械驻车制动，G04只验证带电坡道运行，不声明断电驻坡。
- 驱动器、保险丝、接触器、BMS和电池最终型号未冻结前，相关限值必须与厂家额定和实测结果取更严格者。
- L01不是首轮测试；它必须排在其余18项通过之后，并在软围栏、有线急停和观察员条件下执行。

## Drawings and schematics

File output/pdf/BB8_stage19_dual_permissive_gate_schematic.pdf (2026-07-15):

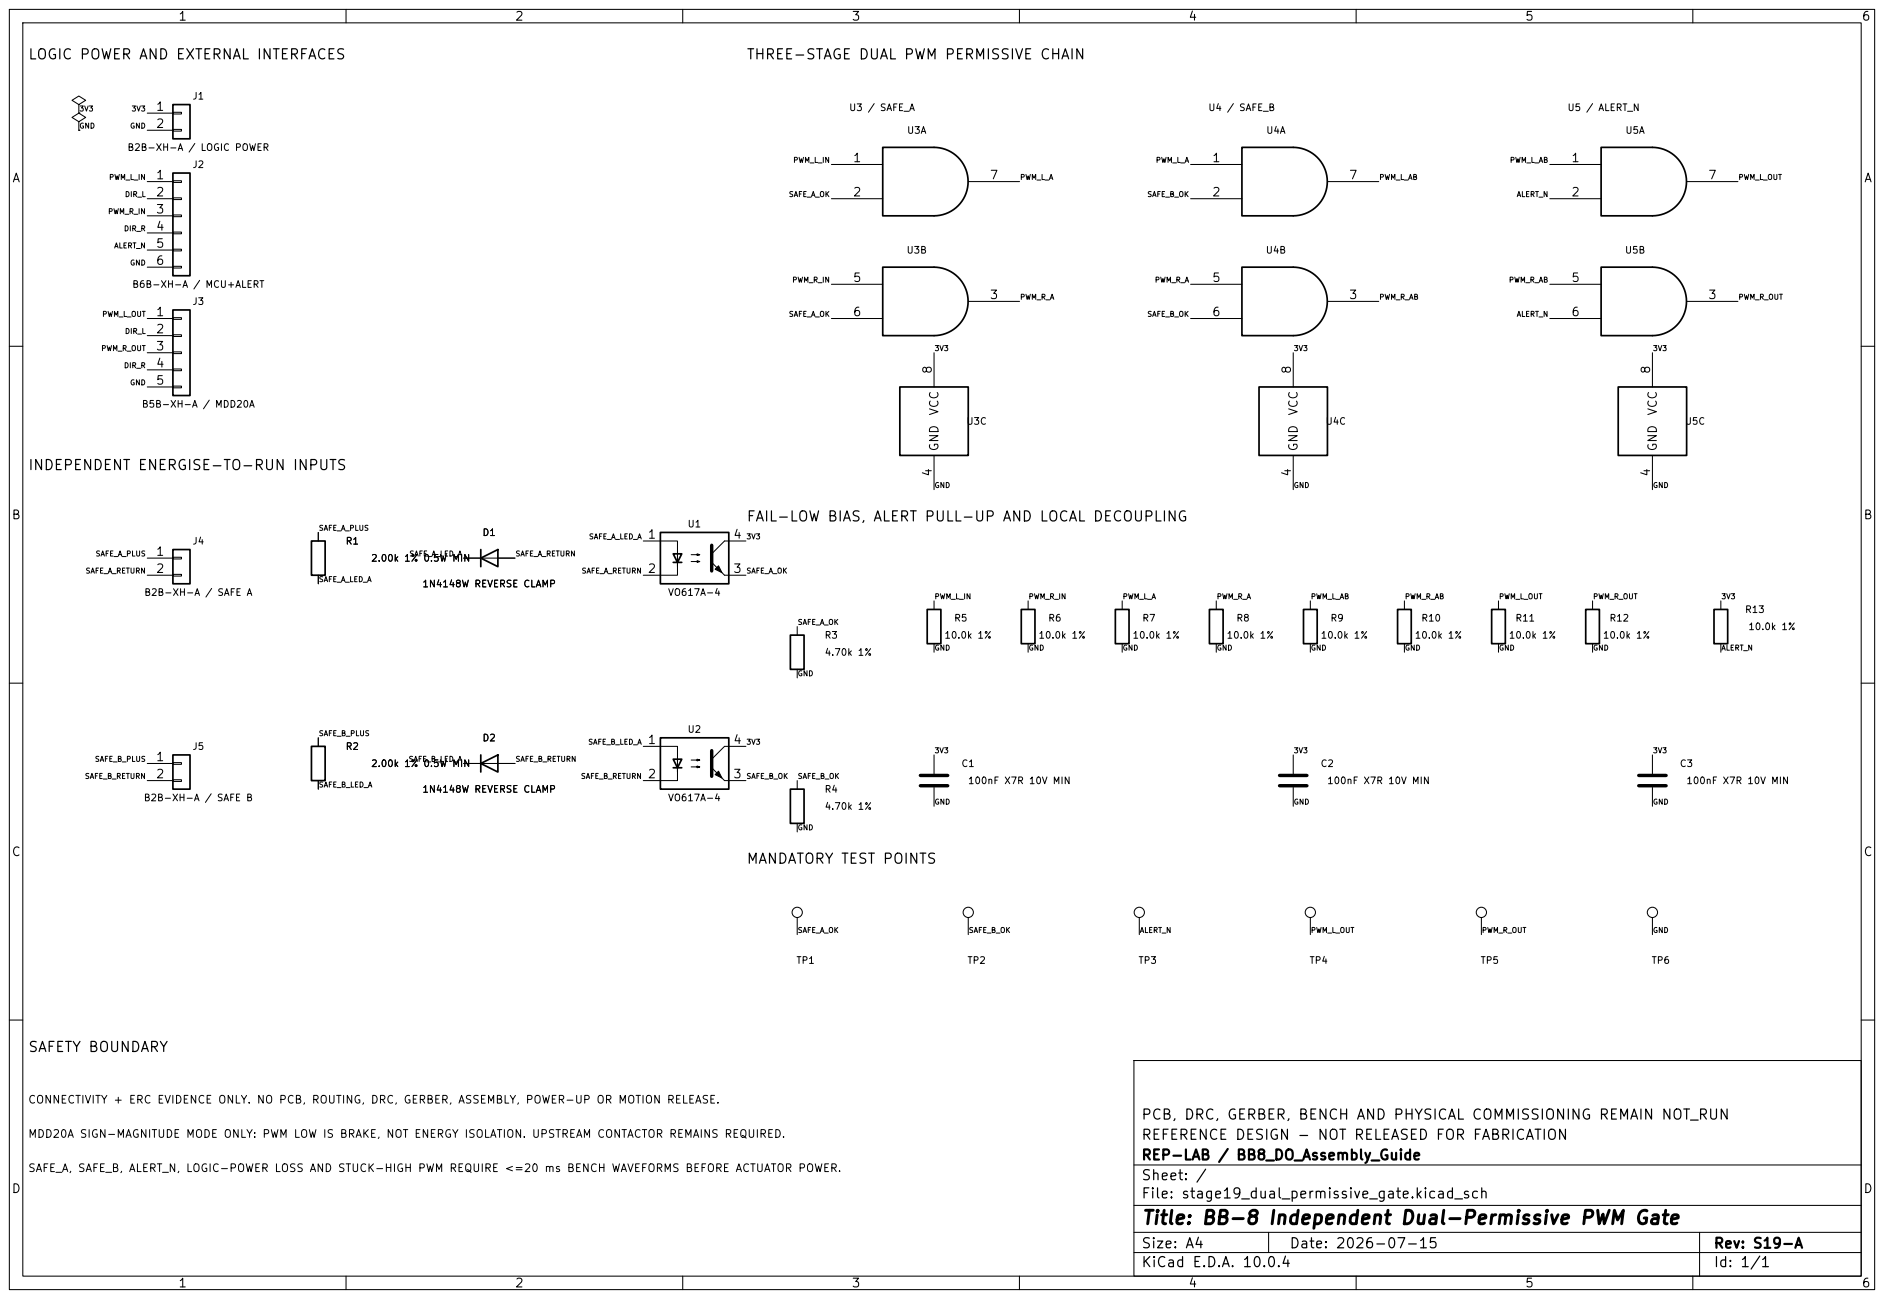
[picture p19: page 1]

LOGIC POWER AND EXTERNAL INTERFACES

U3 / SAFE_A THREE-STAGE DUAL PWM PERMISSIVE CHAIN

INDEPENDENT ENERGISE-TO-RUN INPUTS

SAFE_A, SAFE_B, ALERT_N, LOGIC-POWER LOSS AND STUCK-HIGH PWM REQUIRE <=20 ms BENCH WAVEFORMS BEFORE ACTUATOR POWER. MDD20A SIGN-MAGNITUDE MODE ONLY: PWM LOW IS BRAKE, NOT ENERGY ISOLATION. UPSTREAM CONTACTOR REMAINS REQUIRED. MANDATORY TEST POINTS

CONNECTIVITY + ERC EVIDENCE ONLY. NO PCB, ROUTING, DRC, GERBER, ASSEMBLY, POWER-UP OR MOTION RELEASE.

PCB, DRC, GERBER, BENCH AND PHYSICAL COMMISSIONING REMAIN NOT_RUN
REFERENCE DESIGN - NOT RELEASED FOR FABRICATION
REP-LAB / BB8_DO_Assembly_Guide
Sheet: /
File: stage19_dual_permissive_gate.kicad_sch
Title: BB-8 Independent Dual-Permissive PWM Gate

Size: A4 | Rev: S19-A
KiCad E.D.A. 10.0.4 | Id: 1/1

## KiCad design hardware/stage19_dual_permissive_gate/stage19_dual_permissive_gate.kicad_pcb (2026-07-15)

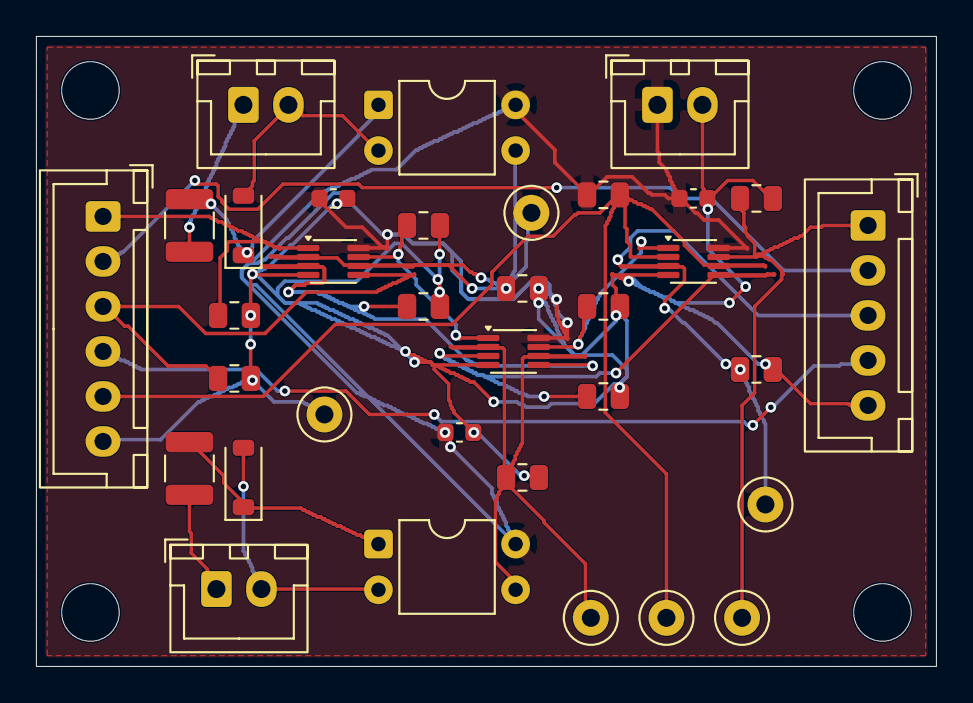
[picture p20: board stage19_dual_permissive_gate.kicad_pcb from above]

Board: 2 copper layers, 50.0 x 35.0 mm, 38 parts (0 on the bottom side), 21 nets.

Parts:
C1, C2, C3: 100nF; C_0603_1608Metric
D1, D2: 1N4148W; D_SOD-123
H1, H2, H3, H4: M3 INSULATED; MountingHole_3.2mm_M3
J1: LOGIC POWER 3V3; JST_XH_B2B-XH-A_1x02_P2.50mm_Vertical
J2: MCU PWM DIR ALERT; JST_XH_B6B-XH-A_1x06_P2.50mm_Vertical
J3: MDD20A PWM DIR; JST_XH_B5B-XH-A_1x05_P2.50mm_Vertical
J4: SAFE A 12-16V8; JST_XH_B2B-XH-A_1x02_P2.50mm_Vertical
J5: SAFE B 12-16V8; JST_XH_B2B-XH-A_1x02_P2.50mm_Vertical
R1, R2: 2.00k 1% 0.5W; R_1210_3225Metric
R3, R4: 4.70k 1%; R_0805_2012Metric
R5, R6, R7, R8, R9, R10, R11, R12, R13: 10.0k 1%; R_0805_2012Metric
TP1: SAFE_A_OK; TestPoint_Loop_D2.50mm_Drill1.0mm
TP2: SAFE_B_OK; TestPoint_Loop_D2.50mm_Drill1.0mm
TP3: ALERT_N; TestPoint_Loop_D2.50mm_Drill1.0mm
TP4: PWM_L_OUT; TestPoint_Loop_D2.50mm_Drill1.0mm
TP5: PWM_R_OUT; TestPoint_Loop_D2.50mm_Drill1.0mm
TP6: GND; TestPoint_Loop_D2.50mm_Drill1.0mm
U1, U2: VO617A-4; DIP-4_W7.62mm
U3, U4, U5: SN74LVC2G08DCU; VSSOP-8_2.3x2mm_P0.5mm

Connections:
3V3: C1.1, C2.1, C3.1, J1.1, R13.1, U1.4, U2.4, U3.8, U4.8, U5.8
ALERT_N: J2.5, R13.2, TP3.1, U5.2, U5.6
DIR_L: J2.2, J3.2
DIR_R: J2.4, J3.4
GND: C1.2, C2.2, C3.2, J1.2, J2.6, J3.5, R3.2, R4.2, R5.2, R6.2, R7.2, R8.2, R9.2, R10.2, R11.2, R12.2, TP6.1, U3.4, U4.4, U5.4
PWM_L_A: R7.1, U3.7, U4.1
PWM_L_AB: R9.1, U4.7, U5.1
PWM_L_IN: J2.1, R5.1, U3.1
PWM_L_OUT: J3.1, R11.1, TP4.1, U5.7
PWM_R_A: R8.1, U3.3, U4.5
PWM_R_AB: R10.1, U4.3, U5.5
PWM_R_IN: J2.3, R6.1, U3.5
PWM_R_OUT: J3.3, R12.1, TP5.1, U5.3
SAFE_A_LED_A: D1.1, R1.2, U1.1
SAFE_A_OK: R3.1, TP1.1, U1.3, U3.2, U3.6
SAFE_A_PLUS: J4.1, R1.1
SAFE_A_RETURN: D1.2, J4.2, U1.2
SAFE_B_LED_A: D2.1, R2.2, U2.1
SAFE_B_OK: R4.1, TP2.1, U2.3, U4.2, U4.6
SAFE_B_PLUS: J5.1, R2.1
SAFE_B_RETURN: D2.2, J5.2, U2.2

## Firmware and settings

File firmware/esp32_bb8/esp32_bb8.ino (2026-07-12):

#include <Arduino.h>
#include <Wire.h>
#include <cmath>

#include "controller_core.h"
#include "power_safety.h"
#include "sensor_math.h"

using bb8::Command;
using bb8::Config;
using bb8::Controller;
using bb8::Output;
using bb8::Sensors;

namespace pins {
constexpr uint8_t kLeftPwm = 4;
constexpr uint8_t kLeftDir = 5;
constexpr uint8_t kRightPwm = 6;
constexpr uint8_t kRightDir = 7;
constexpr uint8_t kDriverEnable = 8;
constexpr uint8_t kEmergencyStop = 9;  // NC loop to GND; open means STOP.
constexpr uint8_t kLeftEncoderA = 10;
constexpr uint8_t kLeftEncoderB = 11;
constexpr uint8_t kRightEncoderA = 12;
constexpr uint8_t kRightEncoderB = 13;
constexpr uint8_t kCurrentAlert = 14;  // Two INA226 ALERT pins wire-OR, active low.
constexpr uint8_t kImuSda = 17;
constexpr uint8_t kImuScl = 18;
constexpr uint8_t kBatteryAdc = 1;
constexpr uint8_t kLeftTempAdc = 2;
constexpr uint8_t kRightTempAdc = 3;
}  // namespace pins

namespace {
constexpr uint32_t kPwmHz = 20000;
constexpr uint8_t kPwmBits = 10;
constexpr uint32_t kPwmMax = (1U << kPwmBits) - 1U;
constexpr uint32_t kControlPeriodUs = 5000;  // 200 Hz.
constexpr uint32_t kRemoteTimeoutMs = 100;
constexpr uint32_t kImuTimeoutMs = 30;
constexpr uint32_t kCurrentTimeoutMs = 20;
constexpr uint32_t kEncoderResponseTimeoutUs = 750000;
constexpr uint16_t kImuCalibrationSamples = 400;  // Two stationary seconds at 200 Hz.
constexpr float kBatteryDividerRatio = 5.55556F;  // 82k high / 18k low.
constexpr float kWheelDiameterM = 0.096F;
constexpr float kEncoderDemandThresholdMps = 0.05F;
constexpr float kSpeedFilterAlpha = 0.20F;
constexpr uint8_t kLeftIna226Address = 0x40;
constexpr uint8_t kRightIna226Address = 0x41;
constexpr float kIna226CurrentLsbA = 0.001F;
constexpr float kIna226ShuntOhm = 0.002F;
constexpr uint16_t kIna226Calibration = 0x0A00;  // 1 mA LSB, 2 mOhm shunt.

struct EncoderState {
  uint8_t pin_a;
  uint8_t pin_b;
  volatile int32_t count{0};
  volatile uint8_t state{0};
  volatile uint32_t last_edge_us{0};
};

struct EncoderSnapshot {
  int32_t count;
  uint32_t last_edge_us;
};

struct ImuRaw {
  int16_t ax;
  int16_t ay;
  int16_t az;
  int16_t gz;
};

Config groundSafeConfig() {
  Config config;
  config.require_motion_feedback = true;
  config.require_current_feedback = true;
  return config;
}

Controller controller(groundSafeConfig());
Command command;
Sensors latest_sensors;
Output latest_output;
bb8::PowerSafetyMonitor power_monitor;
EncoderState left_encoder{pins::kLeftEncoderA, pins::kLeftEncoderB};
EncoderState right_encoder{pins::kRightEncoderA, pins::kRightEncoderB};
portMUX_TYPE encoder_mux = portMUX_INITIALIZER_UNLOCKED;
int32_t previous_left_count = 0;
int32_t previous_right_count = 0;
uint32_t left_demand_start_us = 0;
uint32_t right_demand_start_us = 0;
float encoder_counts_per_wheel_revolution = 0.0F;
int8_t left_encoder_direction = 1;
int8_t right_encoder_direction = 1;
float left_speed_filtered_mps = 0.0F;
float right_speed_filtered_mps = 0.0F;

uint8_t imu_address = 0;
uint32_t last_imu_ms = 0;
uint16_t imu_calibration_count = 0;
float gyro_z_bias_accumulator = 0.0F;
float gyro_z_bias_raw = 0.0F;
bool imu_calibrated = false;
bool ina226_ready = false;
bool ina226_configuration_ok = false;
uint32_t last_current_ms = 0;
uint32_t last_ina_verify_ms = 0;

uint32_t last_command_ms = 0;
uint32_t last_control_us = 0;
uint32_t last_report_ms = 0;
bool pwm_ready = false;

void ARDUINO_ISR_ATTR encoderIsr(void* argument) {
  auto* encoder = static_cast<EncoderState*>(argument);
  const uint8_t current =
      (static_cast<uint8_t>(digitalRead(encoder->pin_a)) << 1U) |
      static_cast<uint8_t>(digitalRead(encoder->pin_b));
  portENTER_CRITICAL_ISR(&encoder_mux);
  encoder->count += bb8::quadratureDelta(encoder->state, current);
  encoder->state = current;
  encoder->last_edge_us = micros();
  portEXIT_CRITICAL_ISR(&encoder_mux);
}

void setupEncoder(EncoderState& encoder) {
  pinMode(encoder.pin_a, INPUT_PULLUP);
  pinMode(encoder.pin_b, INPUT_PULLUP);
  encoder.state =
      (static_cast<uint8_t>(digitalRead(encoder.pin_a)) << 1U) |
      static_cast<uint8_t>(digitalRead(encoder.pin_b));
  encoder.last_edge_us = micros();
  attachInterruptArg(encoder.pin_a, encoderIsr, &encoder, CHANGE);
  attachInterruptArg(encoder.pin_b, encoderIsr, &encoder, CHANGE);
}

EncoderSnapshot snapshotEncoder(const EncoderState& encoder) {
  portENTER_CRITICAL(&encoder_mux);
  const EncoderSnapshot snapshot{encoder.count, encoder.last_edge_us};
  portEXIT_CRITICAL(&encoder_mux);
  return snapshot;
}

bool writeMpuRegister(uint8_t reg, uint8_t value) {
  Wire.beginTransmission(imu_address);
  Wire.write(reg);
  Wire.write(value);
  return Wire.endTransmission(true) == 0;
}

bool readMpuRegister(uint8_t address, uint8_t reg, uint8_t& value) {
  Wire.beginTransmission(address);
  Wire.write(reg);
  if (Wire.endTransmission(false) != 0) return false;
  if (Wire.requestFrom(static_cast<uint16_t>(address), static_cast<uint8_t>(1), true) != 1) {
    return false;
  }
  value = static_cast<uint8_t>(Wire.read());
  return true;
}

bool writeInaRegister(uint8_t address, uint8_t reg, uint16_t value) {
  Wire.beginTransmission(address);
  Wire.write(reg);
  Wire.write(static_cast<uint8_t>(value >> 8U));
  Wire.write(static_cast<uint8_t>(value & 0xFFU));
  return Wire.endTransmission(true) == 0;
}

bool readInaRegister(uint8_t address, uint8_t reg, uint16_t& value) {
  Wire.beginTransmission(address);
  Wire.write(reg);
  if (Wire.endTransmission(false) != 0) return false;
  if (Wire.requestFrom(static_cast<uint16_t>(address), static_cast<uint8_t>(2), true) != 2) {
    return false;
  }
  value = (static_cast<uint16_t>(Wire.read()) << 8U) |
          static_cast<uint16_t>(Wire.read());
  return true;
}

bool setupIna226(uint8_t address) {
  uint16_t manufacturer = 0;
  uint16_t die = 0;
  if (!readInaRegister(address, 0xFE, manufacturer) || manufacturer != 0x5449 ||
      !readInaRegister(address, 0xFF, die) || (die & 0xFFF0U) != 0x2260U) {
    return false;
  }
  return writeInaRegister(address, 0x00, 0x4127) &&
         writeInaRegister(address, 0x05, kIna226Calibration) &&
         writeInaRegister(address, 0x06, 0x0000);  // Alert disabled until explicit limits.
}

bool configureInaAlerts(float instantaneous_trip_a) {
  const float threshold_v = instantaneous_trip_a * kIna226ShuntOhm;
  const uint16_t threshold_counts = static_cast<uint16_t>(
      constrain(std::lround(threshold_v / 0.0000025F), 1L, 32767L));
  const bool limits_written =
      writeInaRegister(kLeftIna226Address, 0x07, threshold_counts) &&
      writeInaRegister(kRightIna226Address, 0x07, threshold_counts);
  const bool masks_written = limits_written &&
      writeInaRegister(kLeftIna226Address, 0x06, 0x8001) &&
      writeInaRegister(kRightIna226Address, 0x06, 0x8001);
  if (!masks_written) {
    writeInaRegister(kLeftIna226Address, 0x06, 0x0000);
    writeInaRegister(kRightIna226Address, 0x06, 0x0000);
  }
  return masks_written;
}

void clearInaAlertLatches() {
  uint16_t ignored = 0;
  readInaRegister(kLeftIna226Address, 0x06, ignored);
  readInaRegister(kRightIna226Address, 0x06, ignored);
}

bool verifyInaConfiguration() {
  uint16_t left_config = 0;
  uint16_t right_config = 0;
  uint16_t left_calibration = 0;
  uint16_t right_calibration = 0;
  return readInaRegister(kLeftIna226Address, 0x00, left_config) &&
         readInaRegister(kRightIna226Address, 0x00, right_config) &&
         readInaRegister(kLeftIna226Address, 0x05, left_calibration) &&
         readInaRegister(kRightIna226Address, 0x05, right_calibration) &&
         left_config == 0x4127 && right_config == 0x4127 &&
         left_calibration == kIna226Calibration &&
         right_calibration == kIna226Calibration;
}

bool readInaCurrent(uint8_t address, float& current_a) {
  uint16_t raw = 0;
  if (!readInaRegister(address, 0x04, raw)) return false;
  current_a = static_cast<int16_t>(raw) * kIna226CurrentLsbA;
  return true;
}

bool updateCurrentSensors(float& left_current_a, float& right_current_a) {
  const uint32_t now_ms = millis();
  if (now_ms - last_ina_verify_ms >= 200) {
    last_ina_verify_ms = now_ms;
    ina226_configuration_ok = ina226_ready && verifyInaConfiguration();
  }
  const bool read_ok = ina226_configuration_ok &&
      readInaCurrent(kLeftIna226Address, left_current_a) &&
      readInaCurrent(kRightIna226Address, right_current_a);
  if (read_ok) last_current_ms = now_ms;
  return read_ok && now_ms - last_current_ms <= kCurrentTimeoutMs;
}

bool setupMpu6050() {
  if (!Wire.begin(pins::kImuSda, pins::kImuScl, 400000U)) return false;
  Wire.setTimeOut(10);
  for (const uint8_t candidate : {uint8_t{0x68}, uint8_t{0x69}}) {
    uint8_t who_am_i = 0;
    if (readMpuRegister(candidate, 0x75, who_am_i) &&
        (who_am_i == 0x68 || who_am_i == 0x69)) {
      imu_address = candidate;
      break;
    }
  }
  if (imu_address == 0) return false;
  return writeMpuRegister(0x6B, 0x01) &&  // Wake, X-gyro PLL clock.
         writeMpuRegister(0x1A, 0x03) &&  // 42/44 Hz DLPF.
         writeMpuRegister(0x1B, 0x08) &&  // Gyro ±500 degrees/s.
         writeMpuRegister(0x1C, 0x08);    // Accelerometer ±4 g.
}

int16_t decodeSigned16(uint8_t high, uint8_t low) {
  return static_cast<int16_t>((static_cast<uint16_t>(high) << 8U) | low);
}

bool readMpu6050(ImuRaw& sample) {
  if (imu_address == 0) return false;
  Wire.beginTransmission(imu_address);
  Wire.write(0x3B);
  if (Wire.endTransmission(false) != 0) return false;
  if (Wire.requestFrom(static_cast<uint16_t>(imu_address), static_cast<uint8_t>(14), true) != 14) {
    return false;
  }
  uint8_t bytes[14];
  for (uint8_t& byte : bytes) byte = static_cast<uint8_t>(Wire.read());
  sample.ax = decodeSigned16(bytes[0], bytes[1]);
  sample.ay = decodeSigned16(bytes[2], bytes[3]);
  sample.az = decodeSigned16(bytes[4], bytes[5]);
  sample.gz = decodeSigned16(bytes[12], bytes[13]);
  return true;
}

void updateImu(Sensors& sensors) {
  ImuRaw sample{};
  const bool read_ok = readMpu6050(sample);
  const bool acceleration_ok = read_ok &&
      bb8::accelerationNormPlausible(sample.ax, sample.ay, sample.az);
  if (read_ok) last_imu_ms = millis();

  if (!imu_calibrated && acceleration_ok && std::abs(sample.gz) < 1000) {
    gyro_z_bias_accumulator += sample.gz;
    ++imu_calibration_count;
    if (imu_calibration_count >= kImuCalibrationSamples) {
      gyro_z_bias_raw = gyro_z_bias_accumulator / imu_calibration_count;
      imu_calibrated = true;
      Serial.printf("IMU_READY address=0x%02x gyro_z_bias_raw=%.2f\n", imu_address, gyro_z_bias_raw);
    }
  }

  sensors.imu_fresh = imu_calibrated && acceleration_ok &&
                      millis() - last_imu_ms <= kImuTimeoutMs;
  if (read_ok) {
    sensors.chassis_tilt_deg = bb8::accelerometerTiltDeg(sample.ax, sample.ay, sample.az);
    sensors.yaw_rate_radps = bb8::mpu6050GyroRawToRadps(sample.gz, gyro_z_bias_raw);
  }
}

float readBatteryV() {
  return analogReadMilliVolts(pins::kBatteryAdc) * 0.001F * kBatteryDividerRatio;
}

float readNtcC(uint8_t pin) {
  constexpr float kSeriesOhm = 10000.0F;
  constexpr float kNominalOhm = 10000.0F;
  constexpr float kNominalK = 298.15F;
  constexpr float kBeta = 3950.0F;
  const float mv = static_cast<float>(analogReadMilliVolts(pin));
  if (mv < 100.0F || mv > 3200.0F) return 125.0F;  // Open/short => over-temp fault.
  const float ntc = kSeriesOhm * mv / (3300.0F - mv);
  const float inv_k = (1.0F / kNominalK) + std::log(ntc / kNominalOhm) / kBeta;
  return (1.0F / inv_k) - 273.15F;
}

void stopHardware() {
  digitalWrite(pins::kDriverEnable, LOW);
  if (pwm_ready) {
    ledcWrite(pins::kLeftPwm, 0);
    ledcWrite(pins::kRightPwm, 0);
  }
}

void writeMotor(uint8_t pwm_pin, uint8_t dir_pin, float normalized) {
  normalized = constrain(normalized, -1.0F, 1.0F);
  digitalWrite(dir_pin, normalized >= 0.0F ? HIGH : LOW);
  ledcWrite(pwm_pin, static_cast<uint32_t>(std::abs(normalized) * kPwmMax));
}

void applyOutput(const Output& output) {
  if (!pwm_ready || !output.enabled) {
    stopHardware();
    return;
  }
  writeMotor(pins::kLeftPwm, pins::kLeftDir, output.left_normalized);
  writeMotor(pins::kRightPwm, pins::kRightDir, output.right_normalized);
  digitalWrite(pins::kDriverEnable, HIGH);
}

// Bench protocol over USB serial:
//   E <counts_per_wheel_rev> <left_sign> <right_sign>  (mandatory after boot)
//   I <instant_trip_A> <stall_A> <stall_ms>             (mandatory after measurement)
//   V <linear_mps> <yaw_radps>                         (send at >=10 Hz)
//   R                                                  (reset only when all sensors are safe)
// Unknown CPR stays at zero and forces encoders_fresh=false, keeping EN disabled.
void readBenchCommand() {
  if (!Serial.available()) return;
  const char type = static_cast<char>(Serial.read());
  if (type == 'V') {
    command.linear_mps = Serial.parseFloat();
    command.yaw_radps = Serial.parseFloat();
    last_command_ms = millis();
  } else if (type == 'E') {
    const float counts = Serial.parseFloat();
    const float left_sign = Serial.parseFloat();
    const float right_sign = Serial.parseFloat();
    if (counts >= 100.0F && (left_sign == 1.0F || left_sign == -1.0F) &&
        (right_sign == 1.0F || right_sign == -1.0F)) {
      encoder_counts_per_wheel_revolution = counts;
      left_encoder_direction = left_sign > 0.0F ? 1 : -1;
      right_encoder_direction = right_sign > 0.0F ? 1 : -1;
      left_demand_start_us = right_demand_start_us = 0;
      Serial.printf("ENCODER_CONFIG_OK cpr=%.1f left=%d right=%d\n", counts,
                    left_encoder_direction, right_encoder_direction);
    } else {
      encoder_counts_per_wheel_revolution = 0.0F;
      Serial.println("ENCODER_CONFIG_REJECTED");
    }
  } else if (type == 'I') {
    const float instantaneous_trip_a = Serial.parseFloat();
    const float stall_current_a = Serial.parseFloat();
    const float stall_timeout_ms = Serial.parseFloat();
    const bool monitor_ok = power_monitor.configure(
        instantaneous_trip_a,
        stall_current_a,
        stall_timeout_ms * 0.001F);
    const bool hardware_ok = monitor_ok && ina226_ready &&
                             configureInaAlerts(instantaneous_trip_a);
    if (hardware_ok) {
      Serial.printf("CURRENT_CONFIG_OK instant=%.2fA stall=%.2fA timeout=%.0fms\n",
                    instantaneous_trip_a, stall_current_a, stall_timeout_ms);
    } else {
      power_monitor.clearConfiguration();
      writeInaRegister(kLeftIna226Address, 0x06, 0x0000);
      writeInaRegister(kRightIna226Address, 0x06, 0x0000);
      Serial.println("CURRENT_CONFIG_REJECTED");
    }
  } else if (type == 'R') {
    if (!bb8::commandIsZeroForReset(command)) {
      Serial.println("RESET_REJECTED_NONZERO_COMMAND");
    } else {
      clearInaAlertLatches();
      latest_sensors.hardware_current_trip = digitalRead(pins::kCurrentAlert) == LOW;
      Serial.println(controller.resetFault(latest_sensors) ? "RESET_OK" : "RESET_REJECTED");
    }
  }
  while (Serial.available() && Serial.read() != '\n') {}
}
}  // namespace

void setup() {
  pinMode(pins::kDriverEnable, OUTPUT);
  pinMode(pins::kLeftDir, OUTPUT);
  pinMode(pins::kRightDir, OUTPUT);
  pinMode(pins::kEmergencyStop, INPUT_PULLUP);
  pinMode(pins::kCurrentAlert, INPUT_PULLUP);
  stopHardware();
  analogReadResolution(12);
  Serial.begin(115200);
  setupEncoder(left_encoder);
  setupEncoder(right_encoder);
  const bool imu_found = setupMpu6050();
  ina226_ready = setupIna226(kLeftIna226Address) && setupIna226(kRightIna226Address);
  ina226_configuration_ok = ina226_ready && verifyInaConfiguration();
  pwm_ready = ledcAttach(pins::kLeftPwm, kPwmHz, kPwmBits) &&
              ledcAttach(pins::kRightPwm, kPwmHz, kPwmBits);
  stopHardware();
  Serial.printf("BB8_SAFE_BOOT pwm=%d imu=%d ina226=%d encoder_cpr=UNCONFIGURED current_limit=UNCONFIGURED\n",
                pwm_ready, imu_found, ina226_ready);
  Serial.println("Keep sphere open and wheels lifted; keep still, then send E, measured I limits, V 0 0, R.");
}

void loop() {
  readBenchCommand();
  const uint32_t now_us = micros();
  if (now_us - last_control_us < kControlPeriodUs) return;
  const float dt_s = (now_us - last_control_us) * 1.0e-6F;
  last_control_us = now_us;

  const EncoderSnapshot left_snapshot = snapshotEncoder(left_encoder);
  const EncoderSnapshot right_snapshot = snapshotEncoder(right_encoder);
  const int32_t left_delta = left_snapshot.count - previous_left_count;
  const int32_t right_delta = right_snapshot.count - previous_right_count;
  previous_left_count = left_snapshot.count;
  previous_right_count = right_snapshot.count;
  const float left_raw_mps = bb8::countsToWheelSpeedMps(
      left_delta * left_encoder_direction,
      encoder_counts_per_wheel_revolution,
      kWheelDiameterM,
      dt_s);
  const float right_raw_mps = bb8::countsToWheelSpeedMps(
      right_delta * right_encoder_direction,
      encoder_counts_per_wheel_revolution,
      kWheelDiameterM,
      dt_s);
  left_speed_filtered_mps += kSpeedFilterAlpha * (left_raw_mps - left_speed_filtered_mps);
  right_speed_filtered_mps += kSpeedFilterAlpha * (right_raw_mps - right_speed_filtered_mps);

  const float expected_left_mps = command.linear_mps - command.yaw_radps * 0.31F * 0.5F;
  const float expected_right_mps = command.linear_mps + command.yaw_radps * 0.31F * 0.5F;
  const bool left_encoder_fresh = bb8::encoderResponseFresh(
      expected_left_mps,
      kEncoderDemandThresholdMps,
      left_snapshot.last_edge_us,
      now_us,
      kEncoderResponseTimeoutUs,
      left_demand_start_us);
  const bool right_encoder_fresh = bb8::encoderResponseFresh(
      expected_right_mps,
      kEncoderDemandThresholdMps,
      right_snapshot.last_edge_us,
      now_us,
      kEncoderResponseTimeoutUs,
      right_demand_start_us);

  Sensors sensors;
  sensors.remote_ok = millis() - last_command_ms <= kRemoteTimeoutMs;
  sensors.emergency_stop = digitalRead(pins::kEmergencyStop) != LOW;
  sensors.battery_v = readBatteryV();
  sensors.motor_temp_c = max(readNtcC(pins::kLeftTempAdc), readNtcC(pins::kRightTempAdc));
  sensors.encoders_fresh = encoder_counts_per_wheel_revolution >= 100.0F &&
                           left_encoder_fresh && right_encoder_fresh;
  sensors.left_wheel_mps = left_speed_filtered_mps;
  sensors.right_wheel_mps = right_speed_filtered_mps;
  updateImu(sensors);
  float left_current_a = 0.0F;
  float right_current_a = 0.0F;
  const bool current_fresh = updateCurrentSensors(left_current_a, right_current_a);
  const bb8::PowerProtectionStatus power_status = power_monitor.update(
      dt_s,
      {
          .sensors_fresh = current_fresh,
          .hardware_trip = digitalRead(pins::kCurrentAlert) == LOW,
          .left_current_a = left_current_a,
          .right_current_a = right_current_a,
          .left_target_mps = expected_left_mps,
          .right_target_mps = expected_right_mps,
          .left_measured_mps = left_speed_filtered_mps,
          .right_measured_mps = right_speed_filtered_mps,
      });
  sensors.current_protection_ready = power_status.configured && power_status.sensors_fresh;
  sensors.hardware_current_trip = power_status.hardware_trip;
  sensors.current_over_limit = power_status.over_current;
  sensors.motor_stalled = power_status.stalled;
  sensors.left_motor_current_a = left_current_a;
  sensors.right_motor_current_a = right_current_a;
  latest_sensors = sensors;

  latest_output = controller.update(dt_s, command, sensors);
  applyOutput(latest_output);

  if (millis() - last_report_ms >= 200) {
    last_report_ms = millis();
    Serial.printf(
        "t_ms=%lu enabled=%d fault=%s cmdV=%.3f cmdW=%.3f batt=%.2f temp=%.1f "
        "estop=%d remote=%d imu=%d enc=%d tilt=%.1f yaw=%.3f "
        "vL=%.3f vR=%.3f iL=%.3f iR=%.3f power=%d hwtrip=%d pwmL=%.3f pwmR=%.3f\n",
        static_cast<unsigned long>(millis()),
        latest_output.enabled,
        bb8::faultName(latest_output.fault),
        command.linear_mps,
        command.yaw_radps,
        sensors.battery_v,
        sensors.motor_temp_c,
        sensors.emergency_stop,
        sensors.remote_ok,
        sensors.imu_fresh,
        sensors.encoders_fresh,
        sensors.chassis_tilt_deg,
        sensors.yaw_rate_radps,
        sensors.left_wheel_mps,
        sensors.right_wheel_mps,
        sensors.left_motor_current_a,
        sensors.right_motor_current_a,
        sensors.current_protection_ready,
        sensors.hardware_current_trip,
        latest_output.left_normalized,
        latest_output.right_normalized);
  }
}

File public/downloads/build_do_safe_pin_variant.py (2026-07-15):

#!/usr/bin/env python3
"""Build a version-locked D-O v3.4.3 Mega safe-servo-pin variant.

The upstream firmware remains in the gitignored third_party checkout under its
custom personal non-commercial terms. This tool publishes only the deterministic
transformation, hashes, compile evidence and wiring contract; it does not publish
the transformed third-party source or a binary.
"""

from __future__ import annotations

import argparse
import csv
import hashlib
import json
import re
import shutil
import subprocess
from datetime import date
from pathlib import Path
from typing import Any


ROOT = Path(__file__).resolve().parents[1]
REPO = ROOT / "third_party" / "D-O-Printed-Droid"
SOURCE_RELATIVE = Path(
    "D-O_ibus_v3.4/D_O_printed_droid_rc_ibus_v3.4.3.ino"
)
SOURCE = REPO / SOURCE_RELATIVE
LICENSE_README = REPO / "D-O_ibus_v3.4/README.md"
EXPECTED_COMMIT = "e90aacdbe26a62fd4f0229d5504a3f2f3c409055"
EXPECTED_SOURCE_SHA256 = (
    "6cb3ce0d96c83724aaf9170eaef592c3d7cc866b9da66819db9e9f3fe134a707"
)
ORIGINAL_SERVO_PINS = {
    "MAINBAR_SERVO_PIN": 0,
    "HEAD1_SERVO_PIN": 1,
    "HEAD2_SERVO_PIN": 5,
    "HEAD3_SERVO_PIN": 6,
}
SAFE_SERVO_PINS = {
    "MAINBAR_SERVO_PIN": 22,
    "HEAD1_SERVO_PIN": 23,
    "HEAD2_SERVO_PIN": 24,
    "HEAD3_SERVO_PIN": 25,
}
STAGE = (
    ROOT
    / "engineering"
    / "do-safe-pin-stage"
    / "D_O_printed_droid_rc_ibus_v3.4.3_safe_pins"
)
STAGED_SOURCE = STAGE / "D_O_printed_droid_rc_ibus_v3.4.3_safe_pins.ino"
BUILD_ROOT = ROOT / "engineering" / "do-safe-pin-build"
CONFIG = ROOT / "engineering" / "arduino-cli-do.yaml"
EVIDENCE = ROOT / "engineering" / "do_safe_pin_variant_compile.json"
PUBLIC_EVIDENCE = ROOT / "public" / "downloads" / EVIDENCE.name
WIRING = ROOT / "engineering" / "do_safe_pin_variant_wiring.csv"
PUBLIC_WIRING = ROOT / "public" / "downloads" / WIRING.name
FQBN = "arduino:avr:mega"


def sha256_bytes(data: bytes) -> str:
    return hashlib.sha256(data).hexdigest()


def sha256_file(path: Path) -> str:
    return sha256_bytes(path.read_bytes())


def git(*args: str) -> str:
    return subprocess.check_output(
        ["git", "-C", str(REPO), *args], text=True
    ).strip()


def numeric_pin_constants(source: str) -> dict[str, int]:
    return {
        name: int(value)
        for name, value in re.findall(
            r"const\s+uint8_t\s+([A-Z0-9_]+_PIN)\s*=\s*(\d+)\s*;",
            source,
        )
    }


def transform_source(source: str) -> tuple[str, dict[str, Any]]:
    observed = numeric_pin_constants(source)
    original_observed = {
        name: observed.get(name) for name in ORIGINAL_SERVO_PINS
    }
    if original_observed != ORIGINAL_SERVO_PINS:
        raise ValueError(
            f"upstream servo pin contract changed: {original_observed}"
        )
    if "Serial.begin(9600);" not in source:
        raise ValueError("expected Serial0 console initialization is missing")

    non_servo_pins = {
        name: pin
        for name, pin in observed.items()
        if name not in ORIGINAL_SERVO_PINS
    }
    occupied_targets = {
        name: pin
        for name, pin in non_servo_pins.items()
        if pin in SAFE_SERVO_PINS.values()
    }
    if occupied_targets:
        raise ValueError(f"safe-pin target collision: {occupied_targets}")
    if len(set(SAFE_SERVO_PINS.values())) != len(SAFE_SERVO_PINS):
        raise ValueError("safe servo pins are not unique")

    transformed = source.replace(
        "// Servos - matched to v1.1/v2.1 pinout",
        "// Servos - BB8/DO guide safe-pin variant; version-locked wiring required",
        1,
    )
    if transformed == source:
        raise ValueError("servo section marker changed upstream")

    for name, old_pin in ORIGINAL_SERVO_PINS.items():
        new_pin = SAFE_SERVO_PINS[name]
        pattern = rf"(const\s+uint8_t\s+{re.escape(name)}\s*=\s*){old_pin}(\s*;)"
        transformed, count = re.subn(
            pattern,
            rf"\g<1>{new_pin}\g<2>",
            transformed,
            count=1,
        )
        if count != 1:
            raise ValueError(f"failed to transform {name}")

    transformed_pins = numeric_pin_constants(transformed)
    safe_observed = {name: transformed_pins.get(name) for name in SAFE_SERVO_PINS}
    if safe_observed != SAFE_SERVO_PINS:
        raise ValueError(f"safe-pin transform mismatch: {safe_observed}")

    return transformed, {
        "original_servo_pins": ORIGINAL_SERVO_PINS,
        "safe_servo_pins": SAFE_SERVO_PINS,
        "released_serial0_pins": [0, 1],
        "other_numeric_pin_constants": non_servo_pins,
        "target_pin_collisions": occupied_targets,
        "serial0_console_preserved": True,
        "all_safe_pins_unique": True,
    }


def parse_compile_output(output: str) -> dict[str, int]:
    program = re.search(
        r"Sketch uses\s+(\d+)\s+bytes\s+\((\d+)%\).*?Maximum is\s+(\d+)\s+bytes",
        output,
        re.DOTALL,
    )
    ram = re.search(
        r"Global variables use\s+(\d+)\s+bytes\s+\((\d+)%\).*?leaving\s+(\d+)\s+bytes.*?Maximum is\s+(\d+)\s+bytes",
        output,
        re.DOTALL,
    )
    if not program or not ram:
        raise ValueError(f"unable to parse Arduino compile summary:\n{output}")
    return {
        "program_bytes": int(program.group(1)),
        "program_percent": int(program.group(2)),
        "program_max_bytes": int(program.group(3)),
        "global_ram_bytes": int(ram.group(1)),
        "global_ram_percent": int(ram.group(2)),
        "global_ram_remaining_bytes": int(ram.group(3)),
        "ram_max_bytes": int(ram.group(4)),
    }
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

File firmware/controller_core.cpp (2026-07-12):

#include "controller_core.h"

#include <algorithm>
#include <cmath>

namespace bb8 {

Controller::Controller(Config config) : config_(config) {}

float Controller::clamp(float value, float low, float high) {
  return std::max(low, std::min(value, high));
}

float Controller::slew(float current, float target, float max_delta) {
  return current + clamp(target - current, -max_delta, max_delta);
}

Fault Controller::checkFault(const Sensors& sensors) const {
  if (sensors.emergency_stop) return Fault::EmergencyStop;
  if (!sensors.remote_ok) return Fault::RemoteLost;
  if (config_.require_motion_feedback && (!sensors.imu_fresh || !sensors.encoders_fresh)) {
    return Fault::MotionSensorStale;
  }
  if (config_.require_motion_feedback) {
    const float encoder_yaw =
        (sensors.right_wheel_mps - sensors.left_wheel_mps) / config_.track_m;
    if (std::abs(encoder_yaw - sensors.yaw_rate_radps) >
        config_.maximum_yaw_sensor_disagreement_radps) {
      return Fault::MotionSensorDisagreement;
    }
  }
  if (config_.require_current_feedback) {
    if (sensors.hardware_current_trip) return Fault::HardwareCurrentTrip;
    if (!sensors.current_protection_ready) return Fault::CurrentSensorStale;
    if (sensors.current_over_limit) return Fault::OverCurrent;
    if (sensors.motor_stalled) return Fault::MotorStall;
  }
  if (sensors.battery_v < config_.minimum_battery_v) return Fault::UnderVoltage;
  if (sensors.motor_temp_c > config_.maximum_motor_temp_c) return Fault::OverTemperature;
  if (std::abs(sensors.chassis_tilt_deg) > config_.maximum_tilt_deg) return Fault::ExcessiveTilt;
  return Fault::None;
}

Output Controller::update(float dt_s, Command command, Sensors sensors) {
  const Fault current_fault = checkFault(sensors);
  if (current_fault != Fault::None && latched_fault_ == Fault::None) latched_fault_ = current_fault;
  if (latched_fault_ != Fault::None || dt_s <= 0.0F) {
    linear_mps_ = 0.0F;
    yaw_radps_ = 0.0F;
    left_integral_ = 0.0F;
    right_integral_ = 0.0F;
    return {.fault = latched_fault_};
  }

  command.linear_mps = clamp(command.linear_mps, -config_.max_wheel_speed_mps, config_.max_wheel_speed_mps);
  const float max_yaw = 2.0F * config_.max_wheel_speed_mps / config_.track_m;
  command.yaw_radps = clamp(command.yaw_radps, -max_yaw, max_yaw);
  linear_mps_ = slew(linear_mps_, command.linear_mps, config_.max_linear_accel_mps2 * dt_s);
  yaw_radps_ = slew(yaw_radps_, command.yaw_radps, config_.max_yaw_accel_radps2 * dt_s);

  float left_target = linear_mps_ - yaw_radps_ * config_.track_m * 0.5F;
  float right_target = linear_mps_ + yaw_radps_ * config_.track_m * 0.5F;
  if (config_.require_motion_feedback) {
    const float yaw_error = yaw_radps_ - sensors.yaw_rate_radps;
    const float yaw_correction = clamp(
        config_.yaw_rate_kp_m_per_rad * yaw_error,
        -config_.maximum_yaw_correction_mps,
        config_.maximum_yaw_correction_mps);
    left_target -= yaw_correction;
    right_target += yaw_correction;
  }
  float power_limit = 1.0F;
  if (sensors.battery_v < config_.battery_derate_start_v) {
    const float span = config_.battery_derate_start_v - config_.minimum_battery_v;
    const float fraction = span > 0.0F
        ? (sensors.battery_v - config_.minimum_battery_v) / span
        : 0.0F;
    power_limit = config_.minimum_power_limit +
                  (1.0F - config_.minimum_power_limit) * clamp(fraction, 0.0F, 1.0F);
  }
  if (sensors.battery_v > 0.0F) {
    power_limit = std::min(power_limit, config_.maximum_motor_voltage_v / sensors.battery_v);
  }
  float left_normalized = left_target / config_.max_wheel_speed_mps;
  float right_normalized = right_target / config_.max_wheel_speed_mps;
  if (config_.require_motion_feedback) {
    const float left_error =
        (left_target - sensors.left_wheel_mps) / config_.max_wheel_speed_mps;
    const float right_error =
        (right_target - sensors.right_wheel_mps) / config_.max_wheel_speed_mps;
    left_integral_ = clamp(
        left_integral_ + config_.wheel_speed_ki_per_s * left_error * dt_s,
        -power_limit,
        power_limit);
    right_integral_ = clamp(
        right_integral_ + config_.wheel_speed_ki_per_s * right_error * dt_s,
        -power_limit,
        power_limit);
    left_normalized += config_.wheel_speed_kp * left_error + left_integral_;
    right_normalized += config_.wheel_speed_kp * right_error + right_integral_;
  }
  const float peak = std::max(std::abs(left_normalized), std::abs(right_normalized));
  if (peak > power_limit) {
    const float scale = power_limit / peak;
    left_normalized *= scale;
    right_normalized *= scale;
  }

  return {
      .left_normalized = left_normalized,
      .right_normalized = right_normalized,
      .limited_linear_mps = linear_mps_,
      .limited_yaw_radps = yaw_radps_,
      .left_target_mps = left_target,
      .right_target_mps = right_target,
      .power_limit = power_limit,
      .enabled = true,
      .fault = Fault::None,
  };
}

bool Controller::resetFault(const Sensors& sensors) {
  if (checkFault(sensors) != Fault::None) return false;
  latched_fault_ = Fault::None;
  linear_mps_ = 0.0F;
  yaw_radps_ = 0.0F;
  left_integral_ = 0.0F;
  right_integral_ = 0.0F;
  return true;
}
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

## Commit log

2026-07-12 publish BB-8 and D-O assembly guide
    [BB8_1to1_screen_referenced.blend, BB8_body_visual_reference_mm.stl, BB8_head_visual_reference_mm.stl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]
2026-07-12 add closed-loop BB-8 motion validation
    [closed_loop_telemetry.csv]
2026-07-12 add ESP32 encoder and IMU sensor adapter
2026-07-12 add INA226 current and stall protection
    [power_safety_replay.csv]
2026-07-12 model stage 13 power safety hardware
    [BB8_1to1_screen_referenced.blend, BB8_internal_mechanism_mm.stl, BB8_stage13_power_safety_hardware.blend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]
2026-07-12 add English guide and stage 14 mass validation
    [BB8_1to1_screen_referenced.blend, BB8_internal_mechanism_mm.stl, BB8_stage14_mass_cg_ballast.blend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]
2026-07-12 add stage 15 drive power and stability gate
    [BB8_1to1_screen_referenced.blend, BB8_internal_mechanism_mm.stl, BB8_stage15_drive_power_estop.blend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]
2026-07-12 add stage 16 physical commissioning evidence gate
    [motor_candidates.json]
2026-07-12 Stage 17: gate drive-power component selection
2026-07-13 Add Stage 18 modular power cassette
    [BB8_1to1_screen_referenced.blend, BB8_internal_mechanism_mm.stl, internal_assembly_manifest.csv]
2026-07-13 add stage 19 dual-permissive PWM gate
    [board_envelope.scad, stage19_gate_board_envelope.scad, stage19_gate_bom.csv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]
2026-07-13 feat: publish stage 19 BB-8 gate evidence and D-O audit
    [BB8_1to1_screen_referenced.blend, board_envelope.scad, do_self_build_bom.csv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]
2026-07-15 feat: expand D-O model and license audit
    [do_self_build_bom.csv]
2026-07-15 feat: add D-O safe servo pin variant
    [do_safe_pin_variant_wiring.csv, do_self_build_bom.csv]
2026-07-15 feat: publish Stage 19 KiCad schematic evidence
    [stage19_dual_permissive_gate.kicad_sch, stage19_gate_bom.csv, stage19_gate_netlist.csv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]
2026-07-15 feat: add Stage 19 routed PCB evidence
    [stage19_dual_permissive_gate.kicad_pcb, stage19_gate_bom.csv]
2026-07-15 feat: add Stage 20 structural load gate
    [stage20_structural_load_sweep.csv]
2026-07-15 feat: add Stage 21 wheel preload cassette gate
    [stage21_crowned_wheel_envelope.stl, stage21_fixed_slider_plate.dxf, stage21_fixed_slider_plate_envelope.stl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]
2026-07-17 feat: add Stage 22 drivetrain interface gate
    [stage22_bearing_retainer.dxf, stage22_drivetrain_interface.scad, stage22_drivetrain_interface_assembly_envelope.stl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]
